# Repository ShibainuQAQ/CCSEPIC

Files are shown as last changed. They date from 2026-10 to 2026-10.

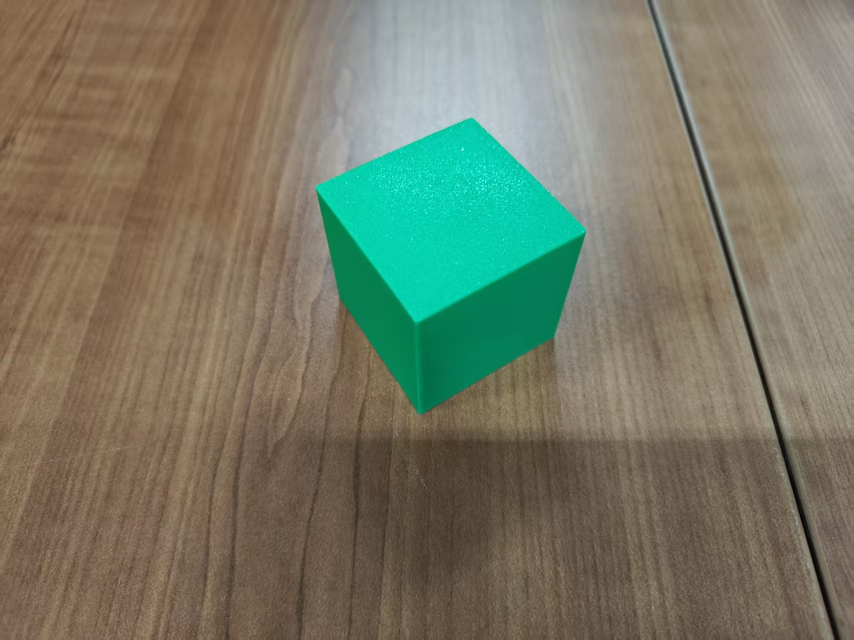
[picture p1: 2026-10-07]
工创赛物料/绿色-正方体.jpg

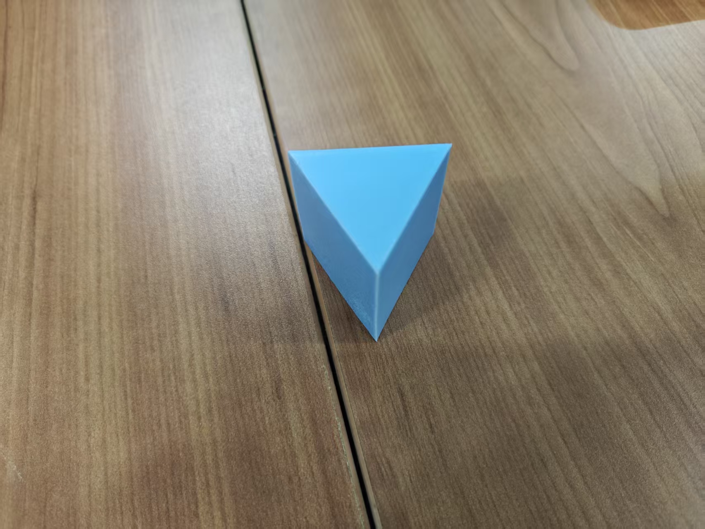
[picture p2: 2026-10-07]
工创赛物料/蓝色-正三棱柱.jpg

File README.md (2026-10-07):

# 工创赛 II-2 智能分拣 · 项目仓库

> 2026 年四川省大学生工程实践与创新能力大赛 · 项目 II-2「智能分拣」
> 龙门式三轴 + 舵机夹爪 · K210 视觉识别（经 PC 处理）· TJC 串口屏显示

---

## 一、任务简介

在 **350×350×450 mm** 的尺寸限制内，制作一台自动分拣装置：**6 个储物盒 + 分拣机构 + 托盘**。

- 待分拣物料边长/直径 ≤ 40 mm，一批 **≥ 12 件、≥ 6 种**（颜色 × 形状组合）
- **同形同色**的物料放入同一个盒，**单盒 ≤ 4 件**
- 每件物料须先**逐件显示**（屏上展示名称/图片/序号）再分下一件
- 物料在搬运中掉落即本轮结束

完整规则见 [`01_规则与命题/`](01_规则与命题/)（官方 PDF + 规则要点提取）。

## 二、总体方案（方案 B）

```
K210 摄像头拍照 ──USB串口(COM5)──▶ PC 端识别（OpenCV + HSV 阈值）
                                      │  两点标定：像素 → 龙门 mm 坐标
                                      ▼
                            PC ──USB-TTL CH340(COM14)──▶ STM32F103C8T6
                                                        ├─ 3× 步进电机（龙门 XYZ）
                                                        ├─ 舵机 Z 轴 / 舵机夹爪
                                                        └─ USART2 ──▶ TJC 串口屏（显示物料名称/图片/计数）
```

- **校赛形态**：K210 直接连 PC，识别与坐标解算全部在 PC 完成，STM32 只负责运动控制（有线，稳定优先）。
- **最终形态**：力争 K210 与 STM32 直连（USART3 已预留，尚未启用），并评估 ESP 无线链路（见 `11_ESP无线调试/`）。

## 三、硬件配置

| 模块 | 型号 / 关键参数 |
|---|---|
| 主控 | STM32F103**C8T6**（64 KB Flash / 20 KB RAM） |
| 视觉 | K210（CanMV_Yahboom 固件） |
| 步进电机 ×3 | 细分后 **80 步/mm**；TIM4 10 kHz 软件步进中断；最高 **5000 Hz ≈ 62.5 mm/s** |
| Z 轴舵机 | MG996R，TIM3-CH3 = **PB0**，50 Hz PWM，脉宽 611~2370 µs（611 = 最低点） |
| 夹爪舵机 | MG996R，TIM3-CH4 = **PB1**，50 Hz PWM，脉宽 750~2140 µs（1850 张开 / 950 闭合 / 2140 松爪投放） |
| 串口屏 | TJC 800×480，USART2（PA2/PA3，9600 8N1），显示物料名称 + 图片 + 序号 + 计数 |

物料实物照片（黄/绿/蓝 × 7 种形状）见 [`工创赛物料/`](工创赛物料/)。

## 四、通信速查

| 链路 | 接口 | 参数 |
|---|---|---|
| PC ↔ STM32 | USART1（PA9/PA10，USB-TTL CH340 = **COM14**） | 115200 **8E1** |
| PC ↔ K210 | K210 USB（**COM5**） | 115200 8N1 |
| STM32 ↔ TJC 屏 | USART2（PA2/PA3） | 9600 8N1 |
| STM32 ↔ K210（预留） | USART3（PB10/PB11） | 未启用 |

> COM 口编号以 `hw_bridge/tools/port_probe.py` 实测为准；无线桥（板载 ESP）已禁用。

## 五、目录结构

| 目录 | 内容 |
|---|---|
| `01_规则与命题/` | 官方规则 PDF、规则要点提取、物料图鉴 |
| `02_方案与说明书/` | 制作思路、校选方案说明书、阶段成果汇报 |
| `03_设计与尺寸/` | 夹爪设计参数、框架与布局尺寸 |
| `04_采购/` | 采购清单、选型问答 |
| `05_工具与校核/` | 布局校核、物料分析、STL/图纸小工具 |
| `06_参考与开源/` | 参考项目（SO-ARM 夹爪等） |
| `07_概念图/` | 框架结构概念图 |
| `09_固件/` | **STM32 固件**：`src/`（C 源码）、`keil/`（Keil 工程）、`build.py`、`flash_keil.ps1`、接线总表 |
| `10_屏幕图片/` | TJC 屏工具：`screen_show.py` 等脚本、图片 ID 对照表、屏内资源 |
| `11_ESP无线调试/` | ESP32-C3/C6 无线方案（固件、说明） |
| `08_视觉/` | **视觉链路**：`vision/`（识别+抓取主脚本）、`omv/`（K210 端）、拍照/REPL 工具 |
| `hw_bridge/` | **PC↔STM32 桥接**：`server.py`、`tools/`（手动控制/抓放脚本）、`protocol.md` |
| `工创赛物料/` | 21 种物料实物照片 |
| `Claude接续日志.md` | 全程接续开发日志（每日进展、踩坑记录） |

## 六、常用操作

```powershell
# 0) 探测串口
python hw_bridge/tools/port_probe.py

# 1) 回安全位（放置点正上方、Z 最高）
python hw_bridge/tools/go_safe.py

# 2) 手动控制（w/s=Z  a/d=夹爪  i/j/k/l=XY  mz/mg/mx=记录  p=状态  x=退出）
python hw_bridge/tools/manual_pick.py

# 3) 视觉引导抓取单件（拍照 → 识别 → mm 坐标 → 抓取 → 放置）
python 08_视觉/vision/vision_pick.py --color yellow --speed 5000 --zsettle 6.0 --zlift 5.0 --gsettle 0.35 --zdn 611 --drop

# 4) 连续抓取某颜色全部物料（第 1 件放 (0,0)，之后每件 -70 mm 排开）
python 08_视觉/vision/vision_pick_all.py --color green

# 5) 两点标定（视觉像素 → 龙门 mm）
python 08_视觉/vision/calibrate_2point.py --dist -40
```

固件：`09_固件/build.py` 编译、`09_固件/flash_keil.ps1` 烧录；协议见 [`hw_bridge/protocol.md`](hw_bridge/protocol.md)。

## 七、当前进度

- ✅ 龙门 XYZ + 舵机夹爪运动控制（软步进 10 kHz）
- ✅ 单件「视觉引导抓取 → 放置」全流程打通
- ✅ TJC 屏显示物料名称/图片/序号（`vis` 控件显隐语义已踩坑确认）
- ⏳ 按颜色连续抓取（`vision_pick_all.py` 已写好，待整机验证）
- ⏳ 形状稳定识别（俯视下 正方体↔正四棱锥、正三棱柱↔正四面体 无法区分，计划倾斜摄像头 20~30° 重标定）
- ⏳ 多盒分配策略（一盒一类、单盒 ≤4 件）、储物盒安装、IR 传感器验证
- ⏳ K210↔STM32 直连（USART3）

## 八、安全须知（重要）

1. **安全位置 = 放置点正上方 Z 最高**，它同时是 **+X 机械极限** —— 任何命令的 X 不得为正（脚本已强制拒绝，除非显式 `--allow-plusx`）。
2. 每次抓放流程以 `ZERO all` 归零开始（以启动时夹爪位置为原点），结束必须 **Z 升到最高、原地停住**，不做多余 XY 移动。
3. Z 轴与夹爪舵机**无位置反馈**，到位判断只能靠固定延时；延时异常变长通常意味着供电不足或机械卡滞（MG996R 堵转 ≈ 2.5 A）。
4. 紧急停机 = 直接断电；异响/顶死立即断电检查。

## 九、文档索引

| 文档 | 路径 |
|---|---|
| 规则要点 | [`01_规则与命题/II-2规则要点与搬运赛道对照.md`](01_规则与命题/II-2规则要点与搬运赛道对照.md) |
| 物料图鉴与识别标定 | [`01_规则与命题/物料图鉴与识别标定.md`](01_规则与命题/物料图鉴与识别标定.md) |
| 接线总表（C8T6） | [`09_固件/接线总表-C8T6-20261004.md`](09_固件/接线总表-C8T6-20261004.md) |
| 串口协议 | [`hw_bridge/protocol.md`](hw_bridge/protocol.md) |
| 屏端 UI 控件表 | [`10_屏幕图片/屏端UI控件表.md`](10_屏幕图片/屏端UI控件表.md) |
| 图片 ID 对照表 | [`10_屏幕图片/图片ID对照表.md`](10_屏幕图片/图片ID对照表.md) |

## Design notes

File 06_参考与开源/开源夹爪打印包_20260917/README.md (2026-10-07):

# 开源夹爪打印包（2026-09-17）

> **队内参考资料，不进比赛提交件。** 许可与来源见 `06_来源与许可.md`。
> 目的：给"龙门 XYZ + 托盘"的分拣机准备一套**能直接打印、抓得稳**的开源夹爪（验证件/对手件）。

## 3 分钟上手

| 步骤 | 做什么 | 去哪 |
|---|---|---|
| 1 | 切片 `01_打印文件\整版_SO-ARM夹爪_154x154_全部件.stl` → PLA+ / 0.2mm / 4 墙 / 25% 填充 / **不开支撑** | 9 个结构件一盘出（154×154×52） |
| 2 | 再打 `补打_固定销x2.stl`（**整版里缺这 2 个小销**）+ `爪垫_锯齿_70x14x2.stl` ×2（TPU 95A） | 齿条/齿轮想更顺可改 0.12mm / 100% 填充单打 |
| 3 | 按 `03_硬件清单与采购.md` 买舵机 / 轴承 / 导杆 / 螺钉 | 原样复刻 ≈ ¥300~420 |
| 4 | 按 `04_装配与调试.md` 装（9 步，含舵机限矩设置） | 关键：**Max Torque Limit = 500** |
| 5 | 抓不牢 / 抓不稳 → 看 `05_抓取稳定性.md` | 结论：瓶颈是**爪面摩擦**，不是夹持力 |

## 三条先知道

| # | 事项 | 说明 |
|---|---|---|
| ① | **它进不了我们的储物盒** | 夹爪外廓 **128（宽）× 109（深）× 130.5（高）mm**，我们盒内只有 **82×82**、盒口距台面 48 —— 塞不进去。用它只能**在盒口上方 20~30mm 投放**（详见 `00_索引与选型.md` §3） |
| ② | **合规** | 工创赛禁"成品套件拼装"、非标件须自主设计制造；A2 创意由专家打分、**同校外形雷同全 0**。这份包**只在队内用**：当验证件、当对手件、当构型参考；正式提交件仍用我方自研夹爪（76mm 宽、能进盒） |
| ③ | **舵机不通用** | 原设计用 **Feetech STS3215（12V 串行总线舵机，RS485/TTL）+ Waveshare 总线转接板**；我们已买的是 **DS3225（PWM，25kg，270°）**。两条路见 `03_硬件清单与采购.md` §2 |

## 目录

| 路径 | 内容 |
|---|---|
| `00_索引与选型.md` | 候选对比表 + 与我们整机的适配核对 + 推荐结论 |
| `01_打印文件\` | **打印就绪**：整版 STL、补打件、爪垫、拆好的单件、摆盘预览图 |
| `02_打印指南.md` | 材料/层高/填充/支撑/后处理/耗时耗材，逐件参数表 |
| `03_硬件清单与采购.md` | 官方 BOM → 国内可买对应表 + 两条舵机路线的取舍 + 预算 |
| `04_装配与调试.md` | 9 步装配（含我们接到 Z 轴要加的转接板）+ 常见故障排查 |
| `05_抓取稳定性.md` | 夹持力/摩擦/回差校核（带算式）+ 抓取姿态规范 + 验收测试 |
| `06_来源与许可.md` | 每个文件从哪个仓库来、什么许可、用它能干什么/不能干什么 |
| `07_其他开源方案\` | 其余候选（SSG-48 自适应夹爪等）的文档与取舍理由 |
| `01_打印文件\单件\` | 从整版拆出的 9 件（已重命名、已贴床），坏一件补一件用 |

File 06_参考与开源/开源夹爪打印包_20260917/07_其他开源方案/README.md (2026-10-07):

# 其他开源方案（本次搜到的其余候选）

> 队内资料，不进比赛提交件。完整对比见上一级 `00_索引与选型.md` §2。

---

## SSG48 自适应电动夹爪

| 项 | 内容 |
|---|---|
| 仓库 | `https://github.com/Source-Robotics/SSG-48-adaptive-electric-gripper`（182★，Apache-2.0） |
| 特点 | **自适应 + 力控**：抓取力 5~80N 可调，行程 48mm，质量 400g；爪指可换（Fin Ray 柔性指 / 实心指 / 尖指） |
| 驱动 | GBM5208-75 云台无刷电机 + **Spectral 无刷 FOC 驱动板（CAN 总线）** + AS5600 磁编码器 |
| 机加工件 | MGN7C 滑块 ×2 + 100mm 直线导轨 + 8mm 联轴器 + 黄铜热熔螺母 ×16 |
| 打印件 | 大件多（单个 body STL 20MB+），耗材与打印时间都不小 |
| 许可 | Apache-2.0 |

**为什么不选它当主推**

1. **驱动板是外部采购件**（source-robotics.com 的 Spectral micro BLDC，CAN 接口）—— 不是"买块舵机就能动"，
   要等货 + 调 CAN + 刷固件，赶工期不划算。
2. 打印量与装配量都远大于 SO-ARM 那套（9 件一版 vs 几十件大件）。
3. 我们需求其实很简单（≤40mm 方块、单件 ≤100g、抓力需求 <5N），**用不上 5~80N 的力控**。

**它值得留下的东西**

| 点 | 对我们的用处 |
|---|---|
| **Fin Ray 柔性指** 思路 | 抓异形/易碎件时，柔性指自动包络 → 若我方货物里有薄壳/纸盒件，可考虑在爪垫上做柔性结构 |
| 力控闭环（编码器 + 电流） | 我方若想判断"夹住了没有/夹多紧"，可参考它的传感方案（我们用总线舵机读负载更省事） |
| BOM 里的 MGN7C 微型导轨 | 与我方 Z 轴/夹爪导向选型是同一类件，可作采购对照 |

> 已下载：`README.md`、`BOM\BOM.md`、`LICENSE`、`SAFETY_WARNING_AND_DISCLAIMER.md`、`Assembly manual\Building_cables.md`。
> 需要它的 STL/STEP 时（单件 20MB+，全量 100MB+）：
> `python "05_工具与校核\gh_mirror.py" get Source-Robotics/SSG-48-adaptive-electric-gripper "<仓库内路径>" --out "_download/SSG48"`

---

## 只能人肉下载的（本机取不到）

| 方案 | 链接 | 为什么取不到 | 值不值得下 |
|---|---|---|---|
| Micro Servo Parallel Gripper（小型平行夹爪，开口 47mm） | https://grabcad.com/library/micro-servo-parallel-gripper-1 | GrabCAD 需登录 | **值得**：形态最贴合我们 82mm 盒口；但驱动是 SG90（力矩太小），要用得换 20kg 舵机并改舵盘接口 |
| Gripper for Servo MG996R | https://www.thingiverse.com/thing:6900287 | Thingiverse 需登录（403） | 一般：MG996R 驱动、CC BY-SA **带传染性**，与"匿名提交"冲突 |
| GRIPPER 标签合集（Printables） | https://www.printables.com/tag/gripper | Printables API 本机超时 | 需要更多灵感时可翻 |
| MSG 步进自适应夹爪（NEMA17，开口可调 200mm） | https://github.com/Source-Robotics/MSG-compliant-AI-stepper-gripper | 可下，但**本体 100/150/200mm 宽** | 不建议：进不了盒 |

---

## 本机网络实况（省得下次再试一遍）

| 通道 | 结果 |
|---|---|
| `github.com` / `raw.githubusercontent.com` 直连 | ❌ 不通 |
| `git clone` / `curl.exe`（Windows schannel） | ❌ `SEC_E_NO_CREDENTIALS (0x8009030E)` —— 换地址也一样 |
| `ghproxy.net` / `gh-proxy.com` + **Python urllib** | ✅ 可用 |
| `cdn.jsdelivr.net` | ❌ 仓库 >50MB 被拒 |
| `api.printables.com`（GraphQL） | ❌ 连接超时 |
| `thingiverse.com` | ❌ HTTP 403（页面里也没有直链 STL，下载要登录） |
| GitHub Search/REST API | ✅ 通（未登录 10 次/分搜索、60 次/时核心） |

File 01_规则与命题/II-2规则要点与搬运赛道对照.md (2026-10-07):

# II-2 智能分拣 · 规则要点与搬运赛道对照

> 依据：《2026年四川省大学生工程实践与创新能力大赛项目II-2：智能分拣项目命题和比赛规则.pdf》（四川省赛区组委会，2026 年 7 月发布，共 8 页，已放入本文件夹）。
> 本文 2026-09-15 由 Claude 用 PyMuPDF 提取全文整理（pdftotext 对该 PDF 提取失败——中文字体无 ToUnicode 映射；PDF 全文为文字、无场地示意图，只有表 1~3，已逐页核对无遗漏）。
> **一句话结论：II-2 是"静态智能分拣装置"，不是移动机器人——没有场地行驶、没有转盘原料区、没有任务码。原搬运方案的底盘/巡线/陀螺仪整套作废，视觉、主控、电源、显示思路大部分要重评。**

---

## 一、新旧赛道总对照

| 维度 | II-1 智能搬运（旧，已弃） | II-2 智能分拣（新，已报名） | 对我方影响 |
|---|---|---|---|
| 作品形态 | 全自主移动小车 | **静态分拣装置**（占地 500×500mm） | ❌ 移动底盘整套作废 |
| 尺寸限制 | 投影≤300×300、高≤400mm（臂可展开） | 整体 **350×350×450mm**（组合式也算整体尺寸） | 限高放宽 50mm，长宽加大 |
| 核心结构 | 底盘+升降台+夹爪 | **储物盒×6 + 分拣机构 + 托盘**（三件可组合可整体） | ➕ 全新机构设计 |
| 任务对象 | ≤80mm、≤100g 物料，6 色 | **≤40mm 见方**的货物，几何体+颜色+**污渍/缺陷图形、文字、二维码**；初赛 ≥12 件、≥6 种 | 货物小一半，识别维度多得多 |
| 视觉任务 | 扫二维码得任务码；认颜色；对圆环 | **AI 识别颜色+形状+文字+图像+二维码**，同形同色归一盒 | 笔记本+USB 摄像头升级为主力，OpenMV 吃力 |
| 显示 | OLED 显示四组任务码，字高≥12mm | **高亮彩屏，能播图片**；逐件显示：序号/货物名称/货物图片/分拣成功总数 | ❌ 2.42 寸单色 OLED 作废，换彩色屏 |
| 场地 | 2400×2400mm 车道场地 | 静态 500×500mm 区域 | 巡线、陀螺仪、定位全不需要 |
| 流程 | 扫码→取料→粗加工→暂存→码垛→返回 | 调试剩 30s 待机→抽签放货入托盘→一键启动→**逐件**分拣，每件存好后**先显示信息再分下一件** | 状态机完全不同 |
| 时间 | 每轮调试 3 分钟+运行 3 分钟，两轮取最好 | **相同**（每轮调试 3 分钟 + 运行 3 分钟，两次机会取最好） | ✅ 不变 |
| 15 秒规则 | 15 秒不动→本轮结束 | 15 秒无动作**或无显示**→本轮结束 | 类似，多了"无显示"判据 |
| 计分风格 | 按环数非线性计分（1环15分…） | **入盒计件**：单货一盒 2 分；同形同色多件同盒每个 5 分；混放不得分；**显示信息每条 2 分** | 满分策略=把同种货物归拢同盒 |
| 成绩换算 | A1/A2/A3 全按名次公式换算 | **A1 改为扣分制**（内容 15 + 排版 5，扣完为止）；A2 专家平均分；B1/B2 按名次公式 | 文档不再是"保底 12 分"，写好直接拿高分 |
| 提交材料 | 报到交 4 份文件+视频 | **任务命题文档 = "决赛任务命题方案"一份**（货物总数/种类/分拣时间/分拣要求；内容质量 15 分+排版 5 分） | 文档工作量大幅减少 |
| 匿名红线 | 同（出现校名姓名等→文档 0 分） | **同**（文档雷同、校名、姓名、队名、特殊标记→0 分） | ✅ 匿名纪律不变 |
| 决赛创新实践 | 4 小时现场做手爪+替换联调 | 4 小时按**现场发布的决赛任务命题**、用现场设备材料完成规定任务（细则另行发布） | 方向待定，强调现场工程能力 |
| 一键启动/禁遥控/单电源内置/允许笔记本通讯 | 有 | **全部保留** | ✅ 不变 |
| 比赛中更换零部件/电源 | 禁止 | 禁止（含调试） | ✅ 不变 |

---

## 二、II-2 规则要点（新赛道的"官方规则要点"，替代日志中搬运版）

### 1. 作品组成与硬性红线（不符合 = 取消资格/成绩）
- 作品 = **储物盒 + 分拣机构 + 托盘** 三部分（可分别制作赛时组合，也可整体式），非标零件必须自主设计制造，**禁止成品套件拼装**。
- **外形尺寸 ≤ 350×350×450mm（长×宽×高）**，无论整体式还是组合式。
- **储物盒 6 个，各自独立**，尺寸形状不限；必须保证分拣的货物（同盒不超过 4 个）能**完全**储存进盒。
  - **建模含义**：单盒内腔须按"**完全容纳 4 件 ≤40mm 货物**"校核，不能只按装 1 件做小；6 盒 × 4 件 = 装置理论容量上限 24 件。
  - **策划含义（写 A1 决赛任务命题方案时）**：同形同色的货物数量**不要超过 4 件**——规则给储物盒定的容量前提就是 4 件，超出即自相矛盾。
  - **初赛含义**：≥12 件且单盒 ≤4 件 → 至少占用 ceil(12/4)=**3 个盒**；均匀分到 ≥6 种时正好用满 6 盒。
- **托盘 ≥ 160×160mm，边缘高 ≥ 10mm**（防货物滑落）。
- 传感器、电机种类数量不限；控制系统种类不限、必须装在装置内；**鼓励采用 AI 技术**。
- **单电源**：只能用一个装在装置内部的电源，种类不限（禁液体/腐蚀污染类），比赛（含调试）中不可更换。**规则无电压上限**（与搬运赛道一致）。
- **允许与笔记本电脑通讯**；运行中不能碰笔记本；**禁止任何方式遥控**（用遥控装置不得参赛）。
- **一键启动**：裁判令下后一键启动；启动后选手再接触装置（含笔记本）→ 本轮结束。
- 比赛（含调试）中**不能更换任何零部件**。
- 显示屏：**高亮、仅显示功能（播放图片用）、能显示各种格式图片**及分拣信息。

### 2. 货物
- 常见几何体、常见颜色；货物上附有**模拟污渍和缺陷的图形、文字、二维码**等信息。
- 尺寸在 **40mm 正方形范围内**（含薄壁货物）。
- **同形状且同颜色的货物 → 放同一个储物盒**。
- 初赛货物 **≥12 件，种类 ≥6 种**（多形状多颜色）。
- 决赛物品按现场发布的决赛任务执行。

### 3. 现场初赛流程
1. 领队会抽签定上场顺序 → 检录 → 抽签定场地号。
2. 进场调试（每轮调试 3 分钟）；**调试剩 30s：停止调试、开电源待机**；同时抽签定本队货物，**裁判随机放入托盘**（位置和方向随机，队员不得触碰，否则本轮结束）。
3. 裁判令下 → **一键启动**，计时开始。
4. 逐件分拣：每分拣一件并存入储物盒后，**显示屏先显示本次分拣信息**（序号、货物名称、货物图片、分拣成功总数量），**然后才能分拣下一件**；信息未显示就分下一件 → 不得分。
5. **15 秒无动作或无显示 → 本轮结束**。
6. 直至完成所有货物分拣。每队**两次运行机会，取最好成绩**。

### 4. 现场初赛计分（A3，70 分）
- 储物盒中只有 1 个货物 → **2 分**。
- 多个**同色同形**货物放同一盒 → **每个 5 分**（货物必须全部入盒，未全入不计数）。
- 不同颜色或不同形状混入同盒（哪怕部分进入）→ 分拣错误，**不得分**。
- 一次只能分拣一件；只能分拣托盘中的货物；**分拣中掉落（装置内或装置外）→ 本轮结束**。
- 正确显示分类信息（序号/名称/图片/成功总数）→ **每条 2 分**；任何错误不得分。

### 5. 成绩构成
| 环节 | 项目 | 分数 | 评定方式 |
|---|---|---|---|
| 初赛 A1 | 任务命题文档 | 20 | **扣分制**（内容质量 15 + 排版规范 5，扣完为止）；雷同/校名姓名 → 0 分 |
| 初赛 A2 | 作品创意设计 | 10 | 现场专家打分取平均：创新性 4 + 美观性 3 + 合理性 3；**同校外形雷同全 0** |
| 初赛 A3 | 现场初赛 | 70 | 见上方计分 |
| 决赛 B1 | 创新实践 | 30 | 名次公式 `30 − 12/(N−1)×(名次−1)`；**4 小时内完成得满分资格，超时不得分**；未按命题完成任务取消后续资格；完成但未在后续比赛应用 → 扣决赛总成绩 50% |
| 决赛 B2 | 现场决赛 | 70 | 名次公式 `70 − 28/(N−1)×(名次−1)`，评分细则同初赛 |

- 同分排序：初赛总成绩同 → 现场初赛分高优先 → 运行时间短优先 → 抽签。决赛同理。
- 关键推论（与搬运不同）：**A1 是扣分制不是名次保底制**——文档写好就能拿满 20，写砸真扣分；排版规范独占 5 分，务必工整。

### 6. 必须提交的材料
- **任务命题文档 = "决赛任务命题方案"**：给出策划的货物分拣任务，含**货物总数量、货物种类、全部货物的分拣时间、具体分拣要求**。内容质量 15 分 + 排版规范 5 分。
- （注意：搬运赛道的"文件 1~4 + 3 分钟视频"结构是 II-1 的；II-2 规则正文只列了任务命题文档一项，**视频等其它材料要求以学校/组委会后续通知为准**。）

### 7. 奖项
- 名额由组委会按参赛队数赛前确定。"未能完成比赛"不参评：未准时参赛 / 严重安全事故或违纪 / 队员资格不符 / 作品不符主题 / 裁判组判定的其它情况。
- 结果公布 24 小时内不提异议不再受理。未尽事宜以组委会补充通知为准。

---

## 三、22 项硬件决策沿用性评审（✅ 2026-09-15 用户已确认评审结论，采购清单已按此重列）

### 大件 8 项（2026-09-11 拍板）

| # | 原决策 | 沿用性 | 说明 |
|---|---|---|---|
| 1 | Emm42 闭环步进 ×4（底盘） | **✏️ 改：数量 4→2~3，用途改为分拣机构驱动** | 装置不动了，但转盘/龙门轴仍需步进；Emm42 正好改做机构轴（数量随机构方案定） |
| 2 | USB 摄像头+笔记本扫码 | **✅ 沿用且升为主力** | AI 识别（形状/颜色/文字/二维码）跑笔记本 OpenCV；规则明确鼓励 AI、允许笔记本通讯 |
| 3 | 2.42 寸 OLED（SPI） | **❌ 作废** | 规则要求能播图片的高亮彩屏 → 换**彩色串口屏**（淘晶驰 3.5 寸级）或 SPI TFT |
| 4 | 6S 5000mAh 25C 航模电池 | **✏️ 改：容量大降** | 没有 4 个驱动电机，功耗大减；若机构用 24V 步进可留 6S 但 2200~3000mAh 足够，也可降 3S/4S——随机构方案定 |
| 5 | 双路 DC-DC（XL4015+LM2596） | **✅ 沿用思路** | 舵机一路+主控一路的架构不变，电压随新舵机定 |
| 6 | DS3225 舵机 ×3+备件 | **✅ 大概率沿用** | 夹爪/拨杆执行器；数量随机构方案定 |
| 7 | 8 路灰度阵列巡线 | **❌ 作废** | 无场地行驶 |
| 8 | 摆式悬挂+配重（本已暂缓） | **❌ 作废** | 无底盘 |

### 待拍板清单 14 项（2026-09-12 拍板）

| # | 原决策 | 沿用性 | 说明 |
|---|---|---|---|
| 1 | OpenMV H7 标准版 | **✏️ 降为辅助** | 形状+二维码+文字识别对 H7 吃力；可做装置端辅助（如入盒确认/兜底识别），也可不买——随视觉方案定 |
| 2 | 1080P USB 摄像头（锁曝光） | **✅ 沿用** | 俯视托盘做 AI 识别主力；锁曝光要求不变 |
| 3 | 96mm 麦轮 ×4 | **❌ 作废** | |
| 4 | 6S 5000~5200mAh 电池 | **✏️ 改** | 同大件 4 |
| 5 | XL4015+LM2596 | **✅ 沿用** | |
| 6 | MPU6050 | **❌ 作废** | 静态装置无需姿态（步进闭环自带位置反馈） |
| 7 | 8 路灰度模块 | **❌ 作废** | |
| 8 | 微动开关 ×5 | **✅ 沿用** | 机构原点/限位、夹爪到位检测照用 |
| 9 | 启动+急停按钮 | **✅ 沿用** | 一键启动是规则硬要求 |
| 10 | CH340 USB 转 TTL | **✅ 沿用** | 笔记本↔主控串口 |
| 11 | 总开关+保险丝+低压报警器 | **✅ 沿用** | 报警器随新电池串数定 |
| 12 | TRVV 拖链电缆 | **✅ 沿用** | 机构运动部件走线更需要拖链 |
| 13 | 联轴器/法兰 | **✏️ 重定** | 随新机构传动定（步进-丝杆/同步带轮） |
| 14 | 升降台方式（未定） | **❌ 作废，并入"分拣机构方案"重新设计** | |

### ➕ 新增需求（搬运方案没有的）
- **彩色显示屏**（能播图片）：串口屏最省事（图片预存屏内，串口发指令翻页）
- **入盒检测**：6 个储物盒各配到位检测（光电对射/反射或微动），因为"货物必须全部入盒才计分"
- **托盘货物定位**：俯视相机标定 + 坐标映射到机构坐标系
- **储物盒×6 + 托盘**结构件（3D 打印/玻纤板/亚克力）

---

## 四、分拣机构方案（✅ 2026-09-15 已拍板：方案 B 龙门 XYZ + 舵机夹爪）

**拍板结论：方案 B**。要点：
- **X/Y 轴**：Emm42 闭环步进（脉冲版）×2 + 同步带传动 + 光轴/直线轴承导轨（开源资料 2 教训：同步带精度高于齿轮齿条）
- **Z 轴**：只需"抓取低位/搬运高位"两个端点 → **DS3225 舵机 + 平行四边形连杆**（保持夹爪姿态），微动开关做到位检测；不上丝杆（负载 <100g，用不上）
- **夹爪**：DS3225 舵机 + 3D 打印夹爪（快拆模块，决赛创新实践可能要现场改制）
- **视觉定位**：USB 摄像头固定在托盘正上方俯视，九点标定把像素坐标映射到托盘平面坐标，直接对应龙门 X/Y 坐标系——这是选 B 的核心原因（相机坐标↔机构坐标一一对应，无运动学解算）
- **布局**：350×350mm 底板上，托盘（160×160）置前方正中，储物盒 2×3 排列于后方/两侧，龙门覆盖全部取放点（具体尺寸三维建模定）
- 步进由 4 套减为 **2 套**，舵机用量 2 个（Z + 夹爪）+ 备件

### 落选方案存档

| 方案 | 落选原因 |
|---|---|
| A. 舵机关节臂 | 开源资料 2 血泪教训：多舵机臂末端重复定位精度差；40mm 小货物+掉落即判负的规则下风险不可接受 |
| C. SCARA 转塔臂 | 需运动学解算、关节间隙影响精度；调试链路比龙门长，对新手队不划算 |
| D. 吹气/拨杆分度盘 | 货物随机姿态落盘不可控，"掉落→本轮结束"规则下直接否决 |

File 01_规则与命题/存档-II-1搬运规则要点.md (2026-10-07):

# 存档：II-1 智能搬运 · 官方规则要点（旧赛道，仅供参考）

> 本文 2026-09-15 由 `Claude接续日志.md` 移出。赛道已换 II-2 智能分拣，本节内容**不再权威、不再维护**，仅因《开源资料1~4》大量引用搬运规则且原 II-1 PDF 已丢失而存档备查。
> 原依据：《2026年四川省大学生工程实践与创新能力大赛项目II-1：智能搬运命题和比赛规则.pdf》（2026 年 7 月，12 页，图 1~图 6 为图片，PDF 已丢失待找回）。

## 一、硬性红线（踩了直接没成绩）
- **尺寸**：铅垂方向投影 ≤ 边长 **300mm 正方形**，高度 ≤ **400mm**（含所有软质线材）。**机械臂允许做成可折叠，出发后可自行展开，展开后尺寸不受限**。
- **电源**：**只能用 1 个装在车体内部的电源，电源种类不限**（不能用液体/有腐蚀污染的），**比赛过程中（含调试）不能更换**。→ **规则原文没有 12V 上限！**
- **一键启动**：车上必须有明确标识的"一键式"启动，**只有一次启动机会**；启动时间到没启动，本轮结束。
- **全自主**：不能用任何方式遥控。**但允许比赛过程中与笔记本电脑通讯**，只是运行中不能碰笔记本、不能遮挡场地（仅允许垂直向下补光）。
- **物料必须放在车上运**：不允许用手爪夹持物料运送；**每次抓1个，放到车上之后才能抓下一个**（车上可带 1~3 个）。物料没放到车上不能往下个区域走（本区域内不受限），否则不计成绩但计时照走。
- **放下即定局**：物料底面一旦接触地面即为放置完毕、按该位置定环数；**再移动该物料，本轮立即结束**。
- **不能推行**：把物料在场地推行移动 → 结束比赛。
- **不能出车道**：离开启停区后只能在灰色车道上行驶，铅垂投影越过车道（机械臂除外）进入其它颜色区域 → 本轮结束。
- **15秒不动**（等转盘时间另加 8 秒）→ 本轮结束。
- **掉落物料不取出**，自行取出 → 本队本轮结束。
- **禁止成品套件拼装**；除标准件外，非标零件必须自主设计制造。比赛期间（含调试）不能更换任何零部件。
- **任务码显示装置**：必须装在车上部醒目位置、**亮光显示**、不被遮挡、**字体高度 ≥ 12mm**，能显示所有任务码及完成情况信息。
- **文档匿名**：文档里出现地名、单位名、姓名、电话号码或无关特殊符号 → **任务命题文档 0 分**。

## 二、场地（2400×2400mm）
- 灰色行车道，中间十字车道宽 **400mm**；四个淡黄色区 450×450mm；其余亚光白色。
- **启停区 ×2**：300×300mm。
- **原料区**：顶面为**直径 300mm 的圆盘**，总高 80~100mm。**电动转盘**，转向随机，转盘上均匀放 3 个物料、**中线呈 120° 夹角**，匀速 **6~10 秒/圈**，停止位置有误差。初赛时转盘转向、停留次数和时间以现场为准。
- **暂存区 / 粗加工区**：各为 **580×150mm**，表面有测量摆放精度的**圆环 1~6 环**，圆环线宽 1.5mm，环中间标数字（就是这个数字决定放哪一环）。
- 原料区、二维码板位置**在规定范围内随机摆放**，以现场为准；各区域尺寸和摆放位置都有偏差，**车必须能适应**。

## 三、环号与分数（非线性，越靠内越值钱）
`φ` = 物料最大直径。环外径：1环 `φ+3`、2环 `φ1+5`、3环 `φ2+7`、4环 `φ3+10`、5环 `φ4+10`、6环 `φ5+10`

| 环号 | 1环 | 2环 | 3环 | 4环 | 5环 | 6环 | 6环外 / 倾倒 |
|---|---|---|---|---|---|---|---|
| 分数 | **15** | 10 | 7 | 5 | 3 | 1 | 0 |

判定方式：物料底面能看到某环的边缘，即算在该环内（图片见图6）。

## 四、物料
- 材质 3D 打印 ABS 或 PLA，**尺寸 ≤80mm，重量 ≤100g**。
- 初赛颜色：红、黄、蓝、绿、黑、浅蓝，**每种颜色两个**（现场会有色差，要能适应）。
- 初赛通过扫码确定需要搬运的**三种不同颜色**的物料，**三种颜色用同一种形状**。
- 决赛物料形状颜色多样（圆柱、方块、三角、球、锥、组合体等），现场公布。

## 五、任务码（⚠️ 是**四组**三位数，不是两组！）
- 共 **4 组三位数**，用 `+` 连接。颜色编号：**红1、黄2、蓝3、绿4、黑5、浅蓝6**。
- 第1组 = 第一批三个物料的**颜色和搬运顺序**
- 第2组 = 第一批物料在**粗加工区和暂存区**的放置位置（环号）
- 第3组 = 第二批三个物料的**颜色和搬运顺序**
- 第4组 = 第二批物料在**粗加工区**的放置位置（第二批在暂存区是码垛，位置由第一批决定，故不单独给）
- 例：`156+123+516+231` → 第一批顺序=红、黑、浅蓝，放在粗加工区/暂存区的 1、2、3 号圆环；第二批顺序=黑、红、浅蓝，放在粗加工区的 2、3、1 号圆环。

> ⚠️ 第2组的精确含义原文表述较含糊（"分别放置在粗加工区和暂存区的1、2、3号圆环上"）。**赛前找裁判或现场确认**：是粗加工区与暂存区共用同一组环号，还是各有分工。

## 六、二维码板
- 每个赛场内侧**垂直**安装 **1 块 A4 大小（横放）** 的二维码板，位置在规定范围内随机摆放。
- 二维码在板子中间，**尺寸 80×80mm（含边框）**，随机产生。

## 七、初赛流程（注意：粗加工区是**中转站**，要搬两次）
1. 扫码读任务码 → **把任务码显示在显示装置上**
2. 到原料区，按顺序从转盘上取第一批 3 个物料**放上车**（每次1个）
3. 携 1~3 个物料 → 运到**粗加工区**，按顺序放到规定圆环上
4. **再把粗加工区的物料取回车上** → 运到**暂存区**，按顺序放到规定圆环上
5. 返回原料区取第二批 3 个 → 重复 2~4（粗加工区）
6. 第二批在暂存区**只能在第一批物料上码垛**：要求**颜色一致**且第一批放置正确，不掉下即得分
7. 回到抽签确定的启停区，检查显示装置上"抓取正确次数 / 放置正确次数"统计是否正确

## 八、计分办法（原始分，用于排名）
1. 正确读二维码并在显示装置上正确显示 → **2 分**
2. 正确顺序码**持续显示到本轮结束** → **2 分**
3. 每正确抓取 1 个物料（抓到并放到车上）→ **2 分**
4. 粗加工区 / 暂存区**平面放置**按环计分（表见上），非线性
5. 暂存区**码垛**得分同第一批分数（不影响第一批平面放置成绩）
6. 规定时间内完成全部流程回到启停区 → **2 分**
7. 返回后正确显示"正确抓取数量 / 正确放置数量"，**各 2 分**（没抓没放则不得分）

## 九、时间与赛制
- 比赛前有 **5 分钟**场地调试时间。
- 比赛**分两轮**，每轮**调试 3 分钟 + 运行 3 分钟**，每队两次运行机会，**取最好成绩**。
- 调试剩余 **1 分钟**时抽签确定搬运任务；剩余 **30 秒**时车必须停止运行、放到出发位待机；助理裁判按抽签放好二维码板、随机摆物料并启动转盘。

## 十、成绩构成与换算（⚠️ 不是直接得分制）
| 环节 | 项目 | 分数 |
|---|---|---|
| 初赛 | 任务命题文档 A1 | 20（起评 12） |
| 初赛 | 作品创意设计 A2 | 10（起评 6） |
| 初赛 | 现场初赛 A3 | 70 |
| 初赛总成绩 A | | 100 |
| 决赛 | 创新实践 B1 | 30（起评 18） |
| 决赛 | 现场决赛 B2 | 70 |
| 决赛总成绩 B | | 100 |

**换算公式（按名次，N = 参赛队数）**：
- `A1 = 20 − 8/(N−1) × (名次−1)` → 区间 12~20
- `A2 = 10 − 4/(N−1) × (名次−1)` → 区间 6~10
- `A3 = 70 − 28/(N−1) × (名次−1)` → 区间 42~70
- `B1 = 30 − 12/(N−1) × (名次−1)` → 区间 18~30
- `B2 = 70 − 28/(N−1) × (名次−1)`

→ **关键推论**：分差被名次压缩，最后一名也能拿 12+6+42 = 60/100。所以**重点是把现场初赛名次顶上去**（A3 跨度 28 分，是三块里最大的），文档和创意设计保底即可、别翻车。文档匿名违规 = 直接 0 分，风险最大。

**同分排序**：初赛总成绩相同 → 现场初赛成绩高者优先 → 运行时间（完成全部任务）短者优先 → 抽签。决赛同分同理。

## 十一、必须提交的材料（初赛第一环节）
**报到时提交**，纸质版一式一份 + 电子版 1 份（**合并为一个 PDF**），共 4 份文件，各 5 分：
1. 作品结构设计方案（5分）
2. 作品控制系统电路设计方案（5分）
3. 决赛任务命题方案（5分）
4. 决赛任务场景策划（5分，含规划决赛场地、放物料区域及位置、物料放置方式，并给出物料形状、尺寸及零件图——工程图 + 三维图）

另需提交**与设计制作有关的不超过 3 分钟的视频 1 份**。除内容质量外，**排版规范、格式装订也计分**。

## 十二、作品创意设计（A2，10分）
- 创新性 4 分（符合主题、外形/内部结构有新意）
- 美观性 3 分（整体美观、合理、实用）
- 合理性 3 分（内外部结构合理、制造精细、拆卸方便）
- ⚠️ **同校作品外形雷同全部给 0 分**

## 十三、决赛
- **创新实践 B1（30分）**：现场抽签物料 → **手爪替换 + 机器人联调**。用现场提供的装备材料，现场设计制作零部件并替换原有零件安装调试。**4 小时内完成得满分，超过 4 小时此项不得分**。未按规定完成零件制作 → 取消资格；未把新加工零件换到作品上完成调试和后续现场运行 → **扣决赛总成绩的 50%**。自带拆装/调试工具。
- **现场决赛 B2（70分）**：流程参照初赛，按现场发布的决赛任务执行，两次机会取最好。

## 十四、奖项
一等奖 ≤10%、二等奖 ≤20%、三等奖 ≤30%。**"未能完成比赛"不参与评奖**（车不能启动 / 任一环节弃权 / 严重安全事故或不守纪律 / 队员资格不符 / 作品不符主题 / 裁判专家组判定的其它情况）。结果公布后 **24 小时内**未提成绩异议不再受理。

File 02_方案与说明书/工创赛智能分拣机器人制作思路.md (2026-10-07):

# 工创赛"智能分拣"赛项 · 制作思路（精简版）

> 面向：四川省赛 · 刚升大二的队伍 · 队内讨论用
> ✅ 已按官方规则核对：同文件夹内《2026年四川省大学生工程实践与创新能力大赛项目II-2：智能分拣项目命题和比赛规则.pdf》（2026年7月发布，共 8 页）
> ⚠️ **2026-09-15 已换赛道：智能搬运（II-1）→ 智能分拣（II-2），报名已确认**。本文已按 II-2 重写。
> 校选阶段一般只要求**方案说明书 + 三维建模**，正式细则以本校教务处/学院通知为准。

---

## 一、我们要做一台什么装置？

**不是车，是一台静态智能分拣机**——放在 500×500mm 的场地里不动，整体尺寸 ≤ 350×350×450mm，由三部分组成：

| 部分 | 要求 |
|---|---|
| **托盘** | ≥160×160mm、边缘高 ≥10mm；比赛时裁判把货物**随机**倒进托盘 |
| **分拣机构** | 我们的方案：**龙门 XYZ 机械手 + 舵机夹爪**（详见第五节） |
| **储物盒 ×6** | 各自独立；同形+同色的货物进同一个盒，每盒最多要能装 4 个 |

按一个按钮后自己完成：

```
俯视摄像头识别托盘里的货物（颜色+形状+文字/二维码）
→ 机械手逐个抓取（一次只能抓 1 个）
→ 放进对应的储物盒（同形同色归一盒）
→ 每放好 1 个，彩色屏先显示「序号/货物名称/图片/分拣成功总数」
→ 显示完了才能抓下一个
→ 直到 12 件以上货物全部分完
```

⚠️ 三个最容易记错的点：
1. **逐件分拣**：一次只能抓 1 个，**显示屏没显示本次信息就抓下一个 = 不得分**。
2. **掉货即终局**：货物掉在装置内或装置外 → **本轮直接结束**。
3. **混盒不得分**：不同颜色或不同形状进了同一个盒（哪怕只进去一半）= 分拣错误，不得分。

💰 **得分大头是"归堆归得对"**：同形同色的多个货物放进同一盒，**每个 5 分**；一盒只有 1 个只得 2 分；每条的显示信息全对每条再得 2 分。

## 二、红线规则（踩了直接没成绩，先背下来）

- **尺寸**：整体（含组合式三部分）≤ **350×350×450mm**；场地占用 500×500mm
- **托盘**：≥160×160mm、边缘 ≥10mm（防货物滑落）
- **储物盒**：**正好 6 个**、各自独立，每盒保证最多 4 个货物能**完全**装入
- **电源**：只能用 **1 个装在装置内部**的电源，种类不限，**赛中（含调试）绝对不能换**。规则**没有电压上限**
- **一键启动**：裁判令下后一键启动；启动后**再碰装置或笔记本 → 本轮结束**
- **全自主**：不能遥控（用遥控装置直接不得参赛）。**允许与笔记本电脑通讯**，但运行中不能碰
- **15 秒规则**：15 秒没有任何动作**或没有显示本次分拣信息** → 本轮结束
- **一次一件**：只能分拣托盘中的货物，一次只能 1 件
- 非标件必须自己设计制造，**禁止成品套件拼装**；赛中和调试期间都不能更换零部件
- **显示屏**：高亮彩屏、仅显示功能、**能播各种格式图片**（单色 OLED 不满足！）
- 文档匿名：**别写校名、姓名、队名、特殊标记**，出现即任务命题文档 **0 分**

## 三、货物与识别任务（先摸清要对付什么）

| 项目 | 参数 |
|---|---|
| 货物尺寸 | **≤40mm 正方形范围内**（含薄壁件）——比想象的还小 |
| 货物种类 | 常见几何体（柱/锥/球/方块…）× 常见颜色；初赛 **≥12 件、≥6 种** |
| 货物上的信息 | **模拟污渍和缺陷的图形、文字、二维码**——识别要能在有干扰的情况下工作 |
| 归类规则 | **形状相同且颜色相同** → 同一个储物盒 |
| 放置方式 | 裁判随机倒入托盘，**位置和方向随机**，队员不许碰 |

⚠️ 这意味着识别系统要同时搞定：**颜色分类 + 形状分类 + 抗污渍干扰 + 文字/二维码**（规则鼓励用 AI）。

## 四、比赛流程与计分（初赛）

**流程**：领队会抽签 → 检录 → 抽场地号 → **调试 3 分钟**（剩 30 秒停止调试、开电源待机，同时裁判抽签定货物并随机倒入托盘）→ 裁判令下**一键启动** → **运行 3 分钟**逐件分拣 → 每队 **2 次运行机会取最好**。

**现场初赛计分（A3，70 分）**：

| 情况 | 得分 |
|---|---|
| 储物盒里只有 1 个货物 | 2 分 |
| 同形同色多个货物同盒 | **每个 5 分**（货物必须全部入盒才算） |
| 不同颜色/形状混进同盒（部分进入也算） | **不得分** |
| 显示信息（序号/名称/图片/总数）每条全对 | 每条 2 分，有错不得分 |
| 没显示信息就分下一件 | 不得分 |
| 货物掉落（装置内外都算） | **本轮结束** |

💡 **策略推论**：尽量把同种货物归拢到同一个盒（5 分/件 vs 2 分/件，差 2.5 倍）；显示信息是白送的分，别因为程序 bug 丢掉。

## 五、推荐方案（预算约 1600~2200 元；明细见同目录《采购清单.md》）

**分拣机构 2026-09-15 已拍板：方案 B「龙门 XYZ + 舵机夹爪」**。为什么是它：

| 候选 | 为什么不是它 |
|---|---|
| 舵机关节臂 | 国特队血泪教训：多舵机臂末端重复定位精度差；货物只有 40mm、掉落直接判负，赌不起 |
| SCARA 转塔臂 | 要解运动学、关节间隙吃精度，调试链长 |
| 吹气/拨杆分度盘 | 货物随机姿态落盘不可控，"掉落=本轮结束"直接否决 |
| **龙门 XYZ** ✅ | 步进精度高、相机俯视坐标与机构坐标**一一对应**（标定简单）、结构成熟、新手成功率最高 |

| 模块 | 选型 | 为什么选它 |
|---|---|---|
| 主控 | **STM32F103RCT6** | 资料最多；2 路步进脉冲 + 2 路舵机 PWM + 串口屏 + 6 路入盒检测，资源够用 |
| 视觉 | **1080P 广角 USB 摄像头（可锁手动曝光）俯视托盘 + 笔记本跑 OpenCV** | 规则鼓励 AI、允许与笔记本通讯；形状+颜色+二维码+文字识别对笔记本是轻活，对单片机视觉模块是硬扛。⚠️ 摄像头硬指标是**能锁手动曝光**，下单前问客服。识别结果串口下发 STM32 |
| X/Y 轴 | **张大头 Emm42 闭环步进（脉冲版）×2 + 同步带 + 光轴导轨** | 闭环步进不丢步；同步带精度高于齿轮齿条（国特队教训）；⚠️ 下单选**脉冲版**别买 CAN 版 |
| Z 轴 + 夹爪 | **DS3225 舵机 ×2（Z 升降用平行四边形连杆 + 夹爪）+ 微动开关到位检测** | Z 只需"高位/低位"两个端点，舵机+连杆就够，不上丝杆；**必须限位开关到位检测，不许只用延时** |
| 入盒检测 | **反射光电开关 ×6（每盒 1 路）** | "货物全部入盒才计分"是硬规则，必须有硬件确认，不开环盲信 |
| 显示 | **淘晶驰 3.5 寸串口屏（480×320）** | 要高亮彩屏+播图片：货物图片按种类预存屏内，单片机串口发指令切换"序号/名称/图片/总数"。⚠️ 别买成裸 TFT |
| 电源 | **单包 6S 锂电 2200~3000mAh + 双路 DC-DC（XL4015 舵机 7.4V + LM2596 主控 5V）+ 6S 平衡充电器** | 没有行走电机，容量比搬运方案降半；24V 仍是步进驱动器推荐电压；**舵机和主控分开供电**（舵机一使劲主控就重启是灵异 bug 之源） |

> 🛒 杂项别漏：一键启动按钮 + 急停开关、CH340 USB 转 TTL、总开关 + 保险丝 + 6S 低压报警器、TRVV 拖链电缆（龙门运动走线反复弯折，国特队灰排线磨破烧 Jetson 的教训）、环形 LED 补光灯。

**架构一句话**：USB 摄像头 + 笔记本负责"看"（识别+定位，结果串口下发），STM32 负责"动"（X/Y 步进、Z 舵机、夹爪、状态机）+ 串口屏显示 + 入盒检测确认。

## 六、四步走路线（大二课业重，按周利用课余时间）

**第 1 步：让机构动起来（2~3 周）**
学 STM32 基础 → 步进驱动器接线（脉冲+方向）→ 定时器发脉冲+加减速 → X/Y 回原点（微动开关）→ 按坐标走位 → 舵机 Z 升降+夹爪开合+到位检测。
*里程碑：串口发"(x,y)"坐标，机械手能走过去抓起一个小方块放回原点。*

**第 2 步：让装置看得见（2~3 周）**
笔记本 OpenCV：俯视图像 → 颜色分割+形状分类（先规则法：轮廓/顶点数/圆度；再上 AI）→ 输出"种类+中心坐标+角度" → 九点标定把像素坐标映射到托盘坐标 → 串口发 STM32。
⚠️ 货物上有模拟污渍/文字/二维码干扰，**颜色形状识别要做抗干扰**（去噪、面积限幅、多次确认）。
*里程碑：托盘里放 6 种货物，屏幕打印出每种的名字和坐标，10 次对 9 次。*

**第 3 步：串起单件分拣全流程（2~3 周）**
识别 → 规划分拣顺序 → 抓取 → 入盒（光电确认）→ 串口屏逐件显示 → 再抓下一件。加入盒检测后做"显示→下一件"的严格时序。
*里程碑：6 件货物连续分拣，成功率 10 轮里 8 轮全对。*

**第 4 步：磨稳定性 + 提速（4 周以上）**
12+ 件压测、异常处理（抓空/卡货/识别存疑重拍）、3 分钟时间预算分配、外壳美观（A2 创意分 10 分看外形+内部结构）。
⚠️ **15 秒无动作或无显示就判负**——每个动作加超时重试，宁可放弃一件也不能卡死整轮。
*里程碑：连续跑 10 轮不死机，12 件 3 分钟内分完。*

## 七、新手最容易踩的 5 个坑

1. **舵机和单片机共电源** → 舵机一使劲单片机就重启，灵异 bug 之源，分开供电
2. **识别不做抗干扰** → 实验室调出阈值就不管，赛场光线不一样全崩；调试那 3 分钟就是干这个的（带旋钮/串口在线调阈值）
3. **只用延时不做到位检测** → 改一次动作链全乱；夹爪/Z 轴都用微动开关确认
4. **先抓下一件再显示** → 规则明文：信息没显示就分下一件不得分；状态机里"显示完成"必须是硬门禁
5. **一个环节卡死就死等** → 15 秒无动作本轮结束；每个动作加超时，识别存疑宁可重拍也不硬抓

## 八、成绩怎么算（别把力气用错地方）

| 环节 | 项目 | 分数 | 怎么评 |
|---|---|---|---|
| 初赛 | 任务命题文档 A1 | 20 | **扣分制**：内容质量 15 + 排版规范 5；雷同/出现校名姓名 → **0 分** |
| 初赛 | 作品创意设计 A2 | 10 | 专家现场打分取平均：创新性 4 + 美观性 3 + 合理性 3；**同校外形雷同全 0** |
| 初赛 | 现场初赛 A3 | 70 | 入盒计件（第四节表） |
| 决赛 | 创新实践 B1 | 30 | 4 小时现场命题任务（用现场设备材料）；名次换算 |
| 决赛 | 现场决赛 B2 | 70 | 流程同初赛；名次换算 `70 − 28/(N−1)×(名次−1)` |

⚠️ 和搬运赛道最大的不同：**A1 文档是扣分制不是名次保底制**——写好"决赛任务命题方案"（货物总数/种类/分拣时间/分拣要求）就能接近满分，写砸是真扣分。**文档值得我们认真写，它是性价比最高的 20 分**。

**报到要交**：任务命题文档一份（即"决赛任务命题方案"）。是否还要视频等材料，以学校/组委会后续通知为准。

⚠️ **决赛"创新实践"环节是 4 小时现场命题任务**（现场提供设备材料）→ 夹爪等执行件做成**可快速更换模块** + 带足备件和工具。
⚠️ **同校作品外形雷同，全部给 0 分**。

## 九、分工建议（3~4 人队）

- **1 人机械**：三维建模 + 3D 打印（龙门架/连杆/夹爪/储物盒/托盘）+ 装配（校选阶段任务最重）
- **1 人电控**：STM32、步进脉冲控制、舵机、入盒检测、串口屏
- **1 人视觉**：笔记本 OpenCV 识别（颜色/形状/抗干扰/二维码）+ 九点标定 + 串口协议
- **队长**：统筹 + 状态机整合 + 文档（**A1 文档 20 分扣分制**，性价比最高，别轻视）

## 十、入门学习清单（按顺序学，边学边做）

1. **C 语言 + STM32 入门**：B 站"江协科技 STM32 入门教程"（免费，新手口碑最好）
2. **步进电机控制**：脉冲 + 方向的原理、梯形/S 曲线加减速、回原点
3. **OpenCV（Python）**：颜色空间（HSV）分割、轮廓与形状特征（顶点数/圆度/Hu 矩）、`QRCodeDetector` 读二维码、相机标定与坐标映射
4. **三维建模**：SolidWorks 或 Fusion 360（校选要交三维模型，3D 打印件也用得上）
5. **串口通信**：STM32 和笔记本各会发会收，定个简单协议（如 `$类型,x,y,角度#`）；淘晶驰串口屏的上位机编辑器用法

## 十一、参考资料

**官方规则（最优先）**
- 同文件夹内《2026年四川省大学生工程实践与创新能力大赛项目II-2：智能分拣项目命题和比赛规则.pdf》
- 同文件夹《II-2规则要点与搬运赛道对照.md》——规则要点整理 + 硬件沿用性评审 + 机构方案对比

**四川赛区通知**
- [西南交通大学 2026 校选报名通知](https://sieetc.swjtu.edu.cn/info/1073/11321.htm)
- [西华大学 2026 校选通知](https://sma.xhu.edu.cn/b1/b3/c669a242099/page.htm)
- [四川大学校内选拔通知](https://jwc.scu.edu.cn/info/1069/9339.htm)
- 大赛官网：http://www.gcxl.edu.cn

**技术参考**
- **同文件夹 `开源\` 目录**：西安理工大学 2025 国特等奖开源方案（4 篇整理稿）。⚠️ 那是**搬运赛道**的移动机器人方案——底盘/巡线部分用不上，但**串口通信架构、闭环步进经验、同步带 vs 齿轮齿条教训、拖链电缆教训、模块化快拆理念**仍然通用
- OpenCV 官方文档、淘晶驰串口屏开发资料（官网有上位机和指令集）

> ⚠️ 开源方案许可为 **CC BY-NC-SA**：禁止商用倒卖，**禁止抄进我们的方案说明书**（比赛要求文档匿名、不抄模板），引用需署名。

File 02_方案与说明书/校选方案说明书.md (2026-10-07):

# 智能分拣装置 · 校选方案说明书

> 版本：2026-09-15（按本赛项 II-2 官方命题要求与评分细则编写）
> 说明：本说明书为匿名评审件，全文不出现校名、姓名、地名与赛项全称。

---

## 1 引言与赛项理解

### 1.1 赛项任务

本赛项要求自主设计并制作一台**静态智能分拣装置**：比赛时裁判将若干货物随机倒入托盘，装置在无任何人工干预的情况下，自动完成货物的**识别、分类与储存**——把形状相同且颜色相同的货物放入同一个储物盒，并在显示屏上逐件显示分拣信息。

### 1.2 规则要点摘要

表 1 规则硬性要求摘要

| 项目 | 要求 |
|---|---|
| 作品组成 | 储物盒 ×6 + 分拣机构 + 托盘（可组合式或整体式） |
| 外形尺寸 | 整体不超过 350×350×450mm（长×宽×高） |
| 托盘 | 不小于 160×160mm，边缘高度不小于 10mm |
| 储物盒 | 6 个独立储物盒；每盒须能完全容纳分拣入盒的货物（不超过 4 个） |
| 货物 | 尺寸在 40mm 正方形范围内（含薄壁件）；附有模拟污渍、缺陷的图形、文字、二维码等信息；初赛货物不少于 12 件、种类不少于 6 种 |
| 归类规则 | 形状相同且颜色相同的货物放入同一个储物盒 |
| 供电 | 仅允许 1 个装在装置内部的电源，种类不限，比赛（含调试）过程中不得更换 |
| 通讯 | 允许与笔记本电脑通讯；运行过程中不得触碰笔记本；禁止任何形式的遥控 |
| 启动 | 裁判指令后一键启动；启动后再次接触装置（含笔记本）本轮结束 |
| 显示 | 高亮显示屏（仅显示功能），支持各种格式图片播放；逐件显示序号、货物名称、货物图片、分拣成功总数量 |
| 时间与轮次 | 每轮调试 3 分钟 + 运行 3 分钟，两次运行机会取最好成绩 |
| 结束条件 | 15 秒无动作或无显示本次分拣信息，本轮结束；货物掉落（装置内或装置外），本轮结束 |

表 2 现场初赛计分规则摘要

| 情况 | 得分 |
|---|---|
| 储物盒中仅有 1 个货物 | 2 分 |
| 多个同色同形货物放入同一储物盒 | 每个 5 分（货物须全部入盒） |
| 不同颜色或不同形状货物混入同盒（含部分进入） | 不得分 |
| 正确显示分类信息（序号/名称/图片/总数） | 每条 2 分，有错不得分 |
| 信息未显示即分拣下一件 | 不得分 |
| 货物掉落（装置范围内或装置外） | 本轮结束 |

### 1.3 设计约束分析

由规则可提炼出四个对设计起决定作用的约束：

表 3 规则约束与设计对策

| # | 规则约束 | 对设计的要求 |
|---|---|---|
| 1 | 掉落即本轮结束，且货物仅 40mm 级 | 抓取与搬运环节的**可靠性与定位精度**是第一指标，机构选型向精度倾斜 |
| 2 | 同形同色归一盒计 5 分/件，混盒不得分 | 识别必须**形状+颜色双判据**，且要有入盒结果的硬件确认 |
| 3 | 逐件分拣，显示完成才能分下一件 | 软件状态机须把"显示完成"作为**硬门禁**，并配合超时机制规避 15 秒判负 |
| 4 | 货物随机倒入托盘，位置方向随机 | 必须**俯视成像 + 坐标标定**，先定位后抓取，不能用固定动作盲抓 |

## 2 机械结构设计

### 2.1 总体布局

装置采用**整体式**布局：底板（350×350mm 级）上，托盘位于前方正中，6 个储物盒分两列布置于后方两侧，龙门架横跨托盘与储物盒上方，俯视相机固定于托盘正上方。整机外形控制在 350×350×450mm 以内。

表 4 整机布局规划

| 区域 | 内容 | 备注 |
|---|---|---|
| 前方中部 | 托盘（160×160mm，边缘高 10mm） | 倒货区，货物随机落入 |
| 托盘正上方 | 俯视相机 + 环形补光 | 固定安装，视野覆盖整个托盘 |
| 后方两侧 | 储物盒 2 列 × 3 个 | 每盒配 1 路入盒检测 |
| 横跨上部 | 龙门架（X/Y 轴）+ Z 升降 + 夹爪 | 工作空间覆盖托盘与全部储物盒 |
| 底板下部/背部 | 主控、电源、驱动器、走线 | 模块化固定，便于拆装检修 |
| 醒目位置 | 彩色显示屏、一键启动按钮、急停开关 | 显示屏不被遮挡 |

### 2.2 分拣机构：龙门 XYZ + 电动夹爪

表 5 机构方案对比与选型（已定论）

| 候选方案 | 优点 | 缺点 | 结论 |
|---|---|---|---|
| 多自由度舵机关节臂 | 结构紧凑、外观科技感强 | 多舵机串联末端重复定位精度差，存在同赛事强队翻车先例；40mm 小货物+掉落判负规则下风险不可接受 | 放弃 |
| SCARA 旋转臂 | 结构较简单 | 需运动学解算，关节间隙影响精度，调试链路长 | 放弃 |
| 吹气/拨杆分度 | 机构最简单 | 货物随机姿态不可控，掉落风险高（掉落即本轮结束） | 放弃 |
| **龙门 XYZ + 电动夹爪** | 直角坐标系精度高、无运动学解算；相机俯视坐标与机构坐标一一对应，标定简单；结构成熟 | 结构件较多、外观偏"工业" | **选用** |

表 6 分拣机构各轴设计

| 轴 | 驱动 | 传动 | 定位方式 |
|---|---|---|---|
| X 轴（横移） | 闭环步进电机（脉冲版） | 同步带 + 光轴直线导轨 | 微动开关回原点 + 闭环步进位置控制 |
| Y 轴（纵移） | 闭环步进电机（脉冲版） | 同步带 + 光轴直线导轨 | 微动开关回原点 + 闭环步进位置控制 |
| Z 轴（升降） | PWM 舵机 | 平行四边形连杆（保持夹爪姿态） | 高位/低位两端点，微动开关低位确认 |
| 夹爪 | PWM 舵机 | 3D 打印夹爪（快拆模块） | 微动开关夹合到位检测 |

选型理由：闭环步进不丢步、位置可控；同步带传动精度高于齿轮齿条（同赛事强队曾因齿轮齿条精度损失分数的公开教训）；Z 轴仅需高位/低位两个端点，舵机加连杆即可满足，无需丝杆，简化结构。

### 2.3 托盘与储物盒

- **托盘**：3D 打印/板材制作，内空 ≥160×160mm，边缘高 10mm；底部平整、浅色哑光，兼顾货物防滑与视觉识别对比度。
- **储物盒 ×6**：3D 打印，独立可拆；盒口做导向斜面便于货物滑入；每盒侧壁开孔安装反射式光电开关，确认货物**完全入盒**（规则：未全部进入不计数）。内腔尺寸按**完全容纳 4 件 ≤40mm 货物**校核（规则要求每盒须能储存不超过 4 个货物），避免因容量不足被判不合格。

### 2.4 模块化与可维护性

- 各功能模块（龙门组件、夹爪组件、储物盒、电控仓）之间采用螺栓连接，**任一模块拆卸不超过 5 颗螺丝**；
- 夹爪为**快拆模块**：决赛创新实践环节需按现场命题改制执行件，快拆结构可最大限度压缩现场改制时间；
- 正式结构件加工前，先用木板/KT 板切样验证装配关系。

## 3 电控系统设计

### 3.1 总体架构

表 7 电控系统组成

| 模块 | 选型 | 职责 |
|---|---|---|
| 主控 | STM32F103RCT6 | 步进脉冲控制、舵机 PWM、状态机、串口通信、入盒检测 |
| X/Y 驱动 | 闭环步进电机驱动器（脉冲版）×2 | 接收脉冲/方向信号，闭环防丢步 |
| Z/夹爪 | 25kg 级 PWM 舵机 ×2 | 升降与开合 |
| 入盒检测 | 反射式光电开关 ×6 | 每盒货物落入确认 |
| 到位检测 | 微动开关 ×5 | X/Y 原点、Z 低位、夹爪到位 |
| 显示 | 3.5 寸串口彩屏（480×320） | 逐件显示序号/名称/图片/总数 |
| 通讯 | USB 转 TTL（CH340） | 笔记本识别结果下发 |

### 3.2 电源系统

表 8 电源分配方案

| 支路 | 电压 | 供电对象 | 实现方式 |
|---|---|---|---|
| 动力支路 | 24V 直通 | 步进驱动器 ×2 | 电池经总开关、保险丝直供 |
| 舵机支路 | 7.4V / 5A | 舵机 ×2 | 独立 DC-DC（XL4015） |
| 逻辑支路 | 5V / 3A | 主控、传感器、显示屏 | 独立 DC-DC（LM2596/Mini360） |

- 电源为**单包 6S（24V）锂聚合物电池**，装于装置内部，符合"单一内置电源、赛中不更换"的要求；
- **舵机与主控分开供电**并在舵机支路就近加储能电容，避免舵机大电流冲击导致主控复位；
- 配备电源总开关、保险丝、低压报警蜂鸣器、急停开关与带标识的一键启动按钮。

### 3.3 可靠性与安全

- 运动机构走线采用柔性拖链电缆，随龙门运动往复弯折不破皮（有赛事中排线磨破导致短路烧毁主控的公开教训）；
- 主回路串联保险丝；急停开关切断动力支路；
- 所有接插件焊接加固，线束整理固定，防止运行振动松脱。

## 4 视觉与识别系统设计

### 4.1 识别任务分析

规则要求识别货物的**颜色、形状、文字、图像、二维码**等信息，且货物带有模拟污渍与缺陷干扰。采用"**笔记本 + 俯视 USB 摄像头**"方案：规则明确允许与笔记本电脑通讯，识别结果经串口下发主控。笔记本算力充足，可运行 OpenCV 完成多特征识别，开发调试效率远高于嵌入式视觉模块。

### 4.2 识别流程

表 9 视觉识别流程

| 步骤 | 内容 |
|---|---|
| 1 取图 | 俯视摄像头固定拍摄托盘；锁定手动曝光 + 环形补光，压制环境光与频闪干扰 |
| 2 分割 | HSV 颜色空间阈值分割得到候选货物区域，形态学去噪、面积限幅（抗污渍干扰） |
| 3 分类 | 颜色直方图判色；轮廓特征（顶点数、圆度、长宽比、Hu 矩）判形状；`QRCodeDetector` 读二维码 |
| 4 定位 | 轮廓质心 + 最小外接矩形给中心坐标与姿态角 |
| 5 标定 | 九点标定建立像素坐标到托盘平面坐标的映射；托盘坐标系与龙门 X/Y 坐标系重合，直接换算目标点 |
| 6 下发 | 识别结果（种类、坐标、角度）经串口定长协议发 STM32 |

### 4.3 抗干扰与确认机制

- 连续多帧识别一致才采信，单帧异常直接重拍；
- 污渍/文字造成的伪轮廓用面积与形状特征双重过滤；
- 调试阶段预留串口在线调阈值接口，适配赛场光线差异。

## 5 软件流程设计

### 5.1 主状态机

表 10 主状态机状态表

| 状态 | 动作 | 转移条件 |
|---|---|---|
| 待机 | 上电自检、各轴回原点、屏显就绪画面 | 一键启动按下 |
| 识别 | 通知笔记本拍摄识别，接收货物清单 | 收到完整清单/超时重拍 |
| 规划 | 按"同形同色归一盒"生成分拣序列与目标盒号 | 序列生成完毕 |
| 取货 | X/Y 移至目标上方 → Z 降 → 夹合（到位确认）→ Z 升 | 夹爪到位开关闭合 |
| 放货 | X/Y 移至目标盒上方 → Z 降 → 松开 → Z 升 | 入盒光电触发确认 |
| 显示 | 串口屏刷新：序号/名称/图片/成功总数 | **显示完成后才允许进入下一件（硬门禁）** |
| 完成/异常 | 全部分完停机；任一动作超时进入重试或放弃该件 | 15 秒判据兜底 |

### 5.2 关键时序与异常处理

- **显示门禁**：状态机中"显示完成"是进入下一次抓取的强制前置条件，对应规则"信息未显示即分拣下一件不得分"；
- **超时与重试**：每个动作设超时；识别存疑重拍、抓空重抓（限次数），宁可放弃一件也不卡死整轮（15 秒无动作本轮结束）；
- **入盒确认**：光电开关未触发则视为未入盒，不计入成功数量，屏显不出现虚假计数。

### 5.3 通讯协议

笔记本 → STM32 单向串口下发，定长帧含帧头校验：货物种类编号、中心坐标、姿态角；STM32 → 串口屏为串口指令（图片与界面元素预存屏内，仅发切换指令，响应快、不占用主控资源）。

## 6 风险分析与对策

表 11 主要风险与对策

| # | 风险 | 后果 | 对策 |
|---|---|---|---|
| 1 | 抓取/搬运中货物掉落 | **本轮直接结束** | 夹爪做仿形内衬+包络式夹持；Z 升降降速；路径避开其它货物；抓取前视觉复核目标位姿 |
| 2 | 污渍/文字干扰导致误分类 | 混盒不得分 | 多帧确认、面积限幅、形状多特征联合判决；存疑重拍 |
| 3 | 赛场光线变化 | 识别率下降 | 锁手动曝光+自带补光；调试 3 分钟内在线调阈值 |
| 4 | 舵机无反馈导致动作不到位 | 抓空/碰货 | 全部动作配微动开关到位检测，禁止纯延时 |
| 5 | 步进低速振动、丢步 | 定位漂移 | 闭环步进防丢步；驱动器细分+加减速曲线抑制振动 |
| 6 | 线束磨破短路 | 设备损坏 | 拖链电缆+缠绕管理线，焊点热缩管绝缘 |
| 7 | 程序卡死 | 15 秒判负 | 全链路超时看门狗，任何环节可放弃当前件保底 |

## 7 进度计划

表 12 四阶段进度

| 阶段 | 内容 | 周期 | 里程碑 |
|---|---|---|---|
| 一 | 机构动起来：步进接线、脉冲与加减速、回原点、舵机与夹爪到位检测 | 2~3 周 | 按坐标走位并抓取小物块 |
| 二 | 装置看得见：颜色/形状/二维码识别、九点标定、串口下发 | 2~3 周 | 6 种货物识别正确率 90% |
| 三 | 单件分拣全流程：识别→抓取→入盒确认→逐件显示→下一件 | 2~3 周 | 6 件连续分拣成功率 80% |
| 四 | 稳定性与提速：12+ 件压测、异常处理、3 分钟时间预算、外壳美观 | 4 周以上 | 连续 10 轮不死机，12 件 3 分钟内完成 |

## 8 附图清单（三维建模完成后补入）

表 13 附图清单

| 图号 | 名称 | 状态 |
|---|---|---|
| 图 1 | 整机三维总装图 | 待补（三维建模中） |
| 图 2 | 龙门 X/Y 传动与导轨布置图 | 待补 |
| 图 3 | Z 升降连杆与夹爪机构图 | 待补 |
| 图 4 | 电源与电控布置图 | 待补 |

---

> 本说明书全部内容为参赛队自主完成；机械非标件均为自主设计并 3D 打印/加工，未使用成品套件拼装。

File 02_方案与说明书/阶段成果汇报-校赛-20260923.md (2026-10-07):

# 智能分拣装置 · 阶段成果汇报（校赛）

> 汇报日期：2026-09-23 ｜ 赛项：大学生工程实践与创新能力大赛 II-2 智能分拣
> 用途：向指导教师汇报项目当前进度与技术成果
> 配套材料：《校选方案说明书》（匿名评审件）、《采购清单》、《框架与布局尺寸》、《夹爪设计参数表》、固件源码与工具脚本

---

## 0. 一页速览

| 项 | 内容 |
|---|---|
| **赛题** | 静态智能分拣装置：货物随机倒入托盘 → 自动识别形状+颜色 → 分入 6 个储物盒 → 屏幕逐件显示 |
| **机构方案** | 已拍板 **方案 B：龙门 XYZ + 舵机夹爪**（经 3 方案对比论证，放弃多关节机械臂） |
| **整机尺寸** | 350 × 350 × 300mm（规则上限 350×350×450，**高度余量 150mm**） |
| **预算** | **约 1050~1600 元**（已剔除全部已有/自备件：步进电机、铝型材、工具、电源杂项等） |
| **投入产出** | 自研文档 **14 份 Word + 20 余份 Markdown**；自研脚本工具 **30+ 个**；固件已跑到 **fw 0.3.0** |
| **当前进度** | 框架已搭；固件主链路全部打通；视觉标定完成；**导轨/电机待装** |
| **距可跑通** | 主干仅剩 5 件，见 §10 |

---

## 1. 赛题理解与规则解析

拿到官方 8 页规则 PDF 后，第一时间完成全文解析并产出三份文档：

| 成果 | 内容 |
|---|---|
| 《II-2规则提取.txt》 | 规则原文逐条提取，供全队引用 |
| 《II-2规则要点与搬运赛道对照.md》 | 要点 + 与上一赛项（II-1 搬运）的逐项对照，**识别出本次已换赛道** |
| 《校选方案说明书》 | 按命题要求与评分细则编写的**匿名评审件**，13 张表 |

**从规则中提炼出 4 条决定设计走向的硬约束：**

| # | 规则约束 | 对设计的要求 |
|---|---|---|
| 1 | 货物掉落 = 本轮直接结束；货物仅 40mm 级 | 抓取与定位**可靠性优先于速度**，机构选型向精度倾斜 |
| 2 | 同形同色归一盒 5 分/件，混盒不得分 | 识别必须**形状+颜色双判据**，且入盒结果要硬件确认 |
| 3 | 显示完成才能分拣下一件；15 秒无动作判负 | 软件状态机须把"显示完成"做成**硬门禁** |
| 4 | 货物随机倒入，方向位置随机，队员不能碰 | 必须**俯视成像 + 坐标标定**，先定位后抓取，禁止固定动作盲抓 |

**计分风险点已全部拆解**：混盒（含部分进入）不得分、货物掉落本轮结束、显示有错该条不得分 —— 这三条决定了"宁可慢、不可错"的整体策略。

---

## 2. 方案选型（已拍板，附论证）

### 2.1 机构方案三选一

| 候选方案 | 优点 | 缺点 | 结论 |
|---|---|---|---|
| 多自由度舵机关节臂 | 结构紧凑、外观科技感强 | 多舵机串联末端重复定位精度差，**同赛事有强队翻车先例**；40mm 小货 + 掉落判负规则下风险不可接受 | ❌ 放弃 |
| 吸盘/真空 | 对规则货物（几何体）吸附不可靠 | 表面有污渍/缺陷图形，且几何体多为小平面 | ❌ 放弃 |
| **龙门 XYZ + 舵机夹爪** | 直角坐标重复定位精度高、控制简单、行程可校核 | 结构相对占地 | ✅ **选定** |

### 2.2 总体布局

- **整体式**：底板 350×350 级，**托盘在前、6 盒（3列×2排）在后**，龙门架横跨上方，俯视相机固定于托盘正上方
- 4040 铝型材框架，立柱落地，导轨梁 2×350 沿深向架在顶框上面，Y 梁吊挂
- 主控、电源、驱动、走线模块化布置于底板下部/背部；屏幕、启动按钮、急停置于醒目不遮挡位置

---

## 3. 机械设计：参数化设计 + 自动校核

> 这是本项目最有方法论价值的部分：**所有尺寸不是拍脑袋定的，而是由脚本按规则硬约束反算、并自动校核**。

### 3.1 框架与下料（4040 铝型材）

| 件 | 长 (mm) | 数量 | 位置 |
|---|---|---|---|
| 立柱 | 260（**待改 310**，见 §3.4） | 4 | 四角落地 |
| 底框横梁 | 270 | 4 | 贴地一圈 |
| 顶框横梁 | 270 | 4 | 顶面与立柱平齐 |
| 导轨梁（深向） | 350 | 2 | 顶框上面，架左右立柱顶面 |
| Y 梁（宽向） | 270 | 1 | 吊在两根导轨梁下面 |

下料合计 ≈4.2m（自备型材，**不进采购预算**）。

### 3.2 工作区布局（已定稿）

| 件 | 宽 X | 深 Y | 说明 |
|---|---|---|---|
| 托盘（外廓 160，壁 2.5） | 95 ~ 255（居中） | 2 ~ 162 | 规则 ≥160×160、边高 ≥10 |
| 储物盒 ×6（外宽 86 / 内腔 82 / 节距 88） | 44 ~ 306 | 168 ~ 342 | 盒组 262×174 |

- 内腔 82 ≥ 4 件 40mm 货所需 80 ✅
- 盒组宽 262 ≤ 内净宽 270（两侧各余 4）✅
- 盒组后沿 342 ≤ 350（余 8）✅
- 托盘与盒组间隙 6mm ✅

### 3.3 行程校核（脚本自动核，10 个取放点逐点全过）

| 轴 | 行程 | 需求 | 余量 |
|---|---|---|---|
| 深向（Y） | 350 − 滑块 45 = **305** | **289**（托盘前沿 y10 → 后排盒心 y299） | ✅ 16 |
| 宽向（X） | Y 梁 270 − 滑块 45 = **225** | **176**（x87 → x263） | ✅ 49 |
| Z（竖直） | 行程 70 | 65（触底 → 高出盒口 20） | ✅ |

**6 个盒心 + 托盘四角共 10 个取放点，深向/宽向逐点核对全部 ✅**（`布局校核报告.txt`）。

同时**主动发现一个次紧点**：深向"前探"差 12.5mm（托盘最前沿的小件够不着，40mm 大件本身够得着），已给出 4 条补救方案并推荐"夹爪相对滑块前移 15mm"（只改一块转接板孔位）。

### 3.4 夹爪 v2（参数化设计，红线全过）

**方案**：1 个 DS3225 舵机 → 小齿轮 → 两根对置齿条 → 两只夹爪（各 1 根 Ø6 导杆 + 2 个微型轴承约束）→ 浮动爪 + 压簧 + 微动开关，实现**恒力夹取 ≈5N + 触货确认**。

| 项 | 数值 | 依据 |
|---|---|---|
| 最大开口 | **64mm** | 40mm 方货斜放 45° 对角 56.6 + 误差 4 + 爪垫压缩 2 = 62.6 → 取 64 |
| 闭口 / 行程 | 8 / **56mm** | 单爪 28 |
| 舵机转角 | **152.8°** | θ = 行程/(2r)，r=10.5 → **必须买 270° 版 DS3225** |
| 爪板 | 厚 3.5 × 深 30 × 高 48，尖端楔形 1.5 | 手指要插进货与盒壁之间 |
| 传动 | 齿轮 M1.5-z14，两段齿带同时啮合上下两根齿条 | 避免两齿条互相干涉 |
| 本体 | 76 × 52 × 34，**总包络 82 高** | 装得进盒口上方又不碰盒壁 |
| 打印件合计 | ≈81g（上界，挖减轻孔可降到 60g 内） | 体积 × PLA 密度 |

**红线校核（`夹爪校核报告.txt`）11 项，10 项 ✅**：抓得住斜放 40mm 方货、整体下潜进盒（爪外廓 71 ≤ 内腔 82）、爪尖楔形可插进缝隙、舵机转角留余量、齿轮装得进主框、舵机同轴直驱、导杆全行程有支撑、包络正确、整机高度 ≤450。

**产出**：`gripper_design.py`（参数化算尺寸+校核+出图+出 STL）、`fusion_gripper.py`（Fusion 360 一键生成实体，833 行/19 个组件）、**11 个 STL 已出**、`夹爪图纸.png`。

**主动发现的 1 个红线问题（待队内拍板）**：内腔 82 + 爪厚 3.5 时，4 件 2×2 可放最大货边只有 **36.5mm**，要放 4 件 40mm 需内腔 ≥88。三条出路：① 换 3030 型材（内净宽 290 → 内腔 90）② 货物上限降到 ≤36 ③ 接受风险靠盒口导角+楔形爪尖提容错。

### 3.5 开源参考（合规使用）

调研 GitHub / Printables / Thingiverse / GrabCAD 后选定 **Robonine《SO-ARM100/101 平行夹爪》**（176★，硬件 CERN-OHL-P-2.0 / 文档 CC BY 4.0），**只借构型、不借零件**，来源与许可已单独成档。已做完整打印包：整版 STL 拆成 9 个单件、按真实件名重命名、补打原厂缺失的 2 个固定销、附 7 份 md+docx 说明。

**两条硬结论**：① 该夹爪 128×109×130.5mm **进不了我们 82mm 盒口** → 定位为验证件/构型参考，正式件仍用自研 v2（76mm 宽）；② 抓不稳的瓶颈是**爪面摩擦（PLA μ≈0.3）不是夹持力**（需求 1.8~4.9N/爪，可用 49N/爪，余量 10~27 倍）→ 对策 = TPU 爪垫 + 齿条齿轮 0.12mm/100% 填充 + 夹货物中上部。

---

## 4. 视觉与识别（基于实测标定，非假设）

### 4.1 货物标定样本

采集官方物料**实拍照片 20 张**（7 形状 × 3 色，缺"蓝色-正方体"1 张），并生成带中文标签的 **7×3 矩阵总览图**供全队对照。

### 4.2 颜色识别窗口（在 20 张实拍照片上实测统计）

| 颜色 | 张数 | H 中位 | H 5%~95% | S 中位 | 建议识别窗（OpenCV 口径） |
|---|---|---|---|---|---|
| 绿 | 7 | 83 | 77~85 | 248 | `H 71~90 & S≥190 & V≥110` |
| 蓝 | 6 | 101 | 100~104 | 150 | `H 93~109 & S≥90 & V≥150` |
| 黄 | 7 | 29 | 22~31 | 140 | `H 16~36 & S≥80 & V≥67` |

**三色 H 彼此间隔 ≥10，判别鲁棒**。同时识别出一个脆弱点：**黄色 H 22~31 与木地板（H 5~20）只隔几个色相单位** → 已定对策：黄判定加饱和度门槛 + 面积滤波、摆放台面用深灰哑光、只用白光照明。

### 4.3 俯视轮廓混淆矩阵（关键发现）

固定俯视相机看到的是投影，**有两组会撞车**：

| 俯视投影 | 可能来源 | 只看轮廓能否区分 | 解法 |
|---|---|---|---|
| 正方形 | 正方体、正四棱锥 | ❌ | **Z 轴下探测高**（棱锥只有方体约 40% 高） |
| 三角形 | 正三棱柱、正四面体 | ❌ | 高度 + 顶面是否可见矩形侧面 |
| 圆 / 六边形 / 五边形 | 圆柱 / 六棱柱 / 五棱锥 | ✅ 各自唯一 | — |

**推荐方案（零成本，硬件已具备）**：把 Z 轴当"高度探针"——在真正夹取前增加一次慢速轻触测高，卡住即停，下降行程即货物高度。**一次测量同时解决两组混淆**，还顺带得到抓取所需的精确下降深度，并提供"深度异常"的兜底判据。

### 4.4 屏幕显示图片（已处理完毕）

20 张货物原图（1706×1279 手机实拍）→ 统一裁成 **160×160**，处理方式为**按颜色自动框出实物 → 外扩留白 → 补正方形 → 缩放**，**20/20 全部自动框选成功**，并生成拼图逐张人工复核。配套 `图片ID对照表.md`（类别 → 图片 ID，运行时按 ID 调用）。

---

## 5. 固件（STM32F103RCT6，已跑到 fw 0.3.0）

### 5.1 架构定位

固件扮演 **"哑执行器 + 安全守门人"**：

- **哑**：只认 ASCII 行协议，收到明确命令才动，动完发事件回报，不猜意图
- **守门人**：**一切安全判断（软限位、未回原点禁动、急停）都在固件里**，上位机不做兜底

> 理由：AI/上位机会犯错（幻觉出越界坐标、命令发一半），让最不可能出错的一层兜住安全，是这套架构唯一站得住的理由。

**线协议 v1.0**：22 条命令、10 个错误码、事件/日志约定，`OK`=受理 / `EVT *_DONE`=完成的语义区分；**每条命令 ≤100ms 内必须回一行**。

### 5.2 已完成的里程碑（全部真机实测通过）

| 里程碑 | 状态 | 实测证据 |
|---|---|---|
| **M1 握手固件** | ✅ 验收通过 | `PING→OK pong`、`VER`、`STATUS`、`HELP`、`ERR 1 unknown`、`ERR 11 not homed` 全部实测 |
| **串口 ISP 自动烧录** | ✅ 打通 | 同步 → V2.2 → DEV_ID `0x0414` → 擦除 → 写入 → 回读校验通过；**不依赖 ST-Link** |
| **编译→烧录→自测全自动闭环** | ✅ | `build.py` + `flash_keil.ps1` 一条命令 |
| **M2 舵机 PWM** | ✅ 打通 | TIM3 双路 50Hz、1µs 分辨率；**Z 轴工作行程标定 600~2400µs**；实测有保位力矩；11 条舵机命令全通 |
| **M2 入盒红外** | ✅ 单路首测通过 | 分体对射，极性实测与固件语义一致；**去抖改为 20ms 非阻塞采样**（5ms×4 连续一致） |
| **串口屏闭环** | ✅ fw 0.3.0 | 淘晶驰 3.5″ USART HMI；回环自检定位到根因 = 出厂波特率 9600；**ASCII 与中文（GBK）两条路都已打通**；UI 实测屏上正确显示 |
| **时基可靠性** | ✅ | `MS?` 实测 MCU 与墙钟误差 **0.08%** |

### 5.3 排障成果（10 个真 bug，全部定位并修复）

这部分是本次汇报中**最能体现工程能力**的内容 —— 每个 bug 症状都极具迷惑性，全部靠自建诊断手段定位：

| # | Bug | 症状（极难查的原因） | 定位手段 |
|---|---|---|---|
| 1 | **向量表下标 = 16 + IRQn**（误写 `[37]`） | 一开中断就跳到地址 0 跑飞；**偏移错了不报错** | RAM 启动脚印 |
| 2 | `GPIOA->CRH` 高低位写反（`0x4B0` 误写 `0xB40`） | TX 配成输入、RX 配成输出 → "固件在跑、串口一个字节出不来" | 寄存器快照进 RAM |
| 3 | 不要用 `__main` | 固件卡在 scatterload / rt_lib_init | 改为自己做 RW 拷贝 + ZI 清零 |
| 4 | **`USART_CR1.M` 字长语义** | F1 上 M 是"含校验位在内"的字长，`M=0+PCE=1` 实际只发 **7 数据位**，PC 按 8E1 读就把校验位当第 8 数据位 | 量化字节账 18→14 |
| 5 | **漏接共地 → MCU 不停复位** | 症状极隐蔽：回复里夹着一条 30 秒前的 banner、夹爪自己跳回中位；**还同时解释了"时基落后 1.8s"和"应答延迟 1.7~5.7s"两个怪现象** | 补共地后立刻不再复位 |
| 6 | 屏出厂波特率 9600 而按 115200 发 | **屏完全不响应且屏幕上毫无异常表现**，是本项目最难查的一类问题 | 回环自检 + 寄存器回读 + 下拉测试 + **垃圾指令探波特率**（决定性一步） |
| 7 | 中文 UTF-8 vs 屏 GBK 字库 | ASCII 正常、中文乱码 | `LCDRAW <hex>` 走 GBK 字节 |
| 8 | 去抖不足（1ms 再采一次不够） | 实测 1ms 内连跳三次 → M4 联调会让 AI 误计数 | 实测日志时间戳 |
| 9 | 对射式"两半没对准" | **误判方向反直觉**：没对准 = 报"有货"，不是报"没货"；临界对准时 19 秒内翻转 25 次 | 状态翻转时刻记录 |
| 10 | 桥 `SerialLink.open()` 成功时不清 `_last_error` | 返回的错误是上一次失败的残留，**被误导 4 次** | 交叉比对 |

**自建的诊断方法论（可复用）**：**RAM 启动脚印**（把"跑到哪一步"写进 SRAM → 复位回 bootloader → 用 Read Memory 读出来），把"板子毫无反应"变成了可判定的事实，是定位 bug 的关键。

### 5.4 引脚与硬件接口（已定稿并实测）

| 部件 | 接口 | 状态 |
|---|---|---|
| 主控 | STM32F103RCT6 最小系统板（板载 CH340K = COM6） | ✅ 实测为高密度 F103 |
| X/Y 步进 | STEP / DIR / EN 脉冲（自备，3.3V 直连） | ⚠️ 待装 |
| Z 轴 / 夹爪 | DS3225 舵机 ×2（TIM3 CH3=PB0 / CH4=PB1） | ✅ PWM 已通，夹爪已接 PB1 |
| 原点/限位/触货 | 微动开关 ×8（用 4 备 4） | 已购 |
| 入盒检测 | 红外对射 ×6（接 PC0~PC5，**3.3V 供电**，非 5V 容忍脚） | 单路已测，10 对已到货 |
| 串口屏 | USART3 / PB10 / PB11，8N1 @9600 | ✅ 闭环 |
| 烧录 | ST-Link V2 ／ 串口 ISP 兜底 | ✅ 两条路都通 |

---

## 6. 上位机接入与工具链（30+ 自研脚本）

为"AI 能直接驱动硬件"搭了一条完整工具链：

| 类别 | 工具 | 作用 |
|---|---|---|
| **硬件桥** | `hw_bridge\server.py`（10 个工具）+ `protocol.md` | 串口收发 / 相机抓拍回传 / **MCU 烧录（AN3155）**，让 AI 直接操作板子与相机 |
| **布局校核** | `layout_check.py` | 外廓/红线/10 取放点逐点行程覆盖，输出《布局校核报告.txt》 |
| **框架校核** | `maycad_check.py` / `maycad_view.py` | 读 MayCAD `.scene`，红线校核外廓/总高/立柱顶/导轨行程/Y 梁净空 |
| **夹爪设计** | `gripper_design.py` / `fusion_gripper.py` | 参数化算尺寸 + 校核 + 出图 + 出 STL；Fusion 一键生成实体 |
| **STL 处理** | `stl_tool.py` / `grip_pad_gen.py` | 量尺寸 / 拆件 / 摆盘 / 正交渲染；**自研 TPU 锯齿防滑爪垫生成器** |
| **视觉标定** | `material_analysis.py` / `material_sheet.py` / `img_tool.py` | 批量分析物料照片出 HSV 统计；拼 7×3 矩阵总览图；货物图片 160×160 自动框选 |
| **固件构建** | `build.py` / `flash_keil.ps1` / `tools\`（9 个诊断脚本） | Python 驱动 armclang（无 make）；编译→烧录一条命令；波特率/校验位扫掠、舵机点动标定、原始抓包 |
| **文档流水线** | `md转word.py` / `docx_colors.py` | Markdown → Word（用 Word 自身排版引擎）；**提取 Word 批注 + 字体颜色**（用于带色批注的清单回收） |
| **下载镜像** | `gh_mirror.py` / `gh.py` / `gh_scan.py` | GitHub 镜像下载器（调研开源方案用） |

---

## 7. 采购与预算

**已按"剔除全部已有/自备件"重列**，预算 **约 1050~1600 元**（原 1600~2200，省下步进电机、铝型材、3D 耗材、电源杂项、全部工具）。

| 类别 | 小计 |
|---|---|
| A 主控 | 35~70 元 |
| B 视觉 | 70~120 元 |
| C 运动与执行（舵机+线轨+同步带+光轴+夹爪增补） | 390~570 元 |
| D 传感器 | 30~45 元 |
| E 显示 | 60~90 元 |
| F 电源（只剩电池+充电器） | 280~430 元 |
| G 线材与连接 | 95~130 元 |
| H 结构材料（板材/标准件） | 90~130 元 |
| **合计** | **约 1050~1600 元** |

**三批下单策略**：① 立即（到货周期长且"动起来/看得见"阶段全要用）：主控、相机、补光、舵机（270°版）、电池+充电器 ② 建模前（便宜件一次凑齐）③ 建模定稿后**按图买**（同步带长度、导轨长度、光轴长度、板材尺寸全部按三维图定，不拍脑袋）。

**已完成的选型闭环**：18 张表的《选型问答整理》覆盖补光灯、同步带、MGN 导轨、角码、电缆、硅胶线、储物盒放置、入盒传感器、清单 9 条批注逐条解答 —— 每项都给出**决定性数值**而非模棱两可。

---

## 8. 文档体系（14 份 Word + 20 余份 Markdown）

| 目录 | 内容 |
|---|---|
| `00_待办与拍板\` | 待拍板事项通俗版（给队友的白话版，每项"要定什么/为什么/推荐哪个"） |
| `01_规则与命题\` | 规则原文提取、要点对照、**物料图鉴与识别标定**（7 张表） |
| `02_方案与说明书\` | 制作思路、**校选方案说明书**（匿名评审件，13 张表） |
| `03_设计与尺寸\` | **框架与布局尺寸**、**夹爪设计参数表**、夹爪目录（源码/STL/图纸/校核报告/交接/用法） |
| `04_采购\` | 采购清单（10 张表）、选型问答整理（18 张表） |
| `05_工具与校核\` | 全部脚本 + 布局校核报告 |
| `06_参考与开源\` | SO-ARM 开源夹爪（含许可合规）、成包打印包（36 文件）+ 7 份说明 |
| `08_发给队友\` | 夹爪设计包（18 文件 ZIP，可直接发） |
| `09_固件\` | 固件源码、Keil 工程、构建/烧录/诊断脚本、**固件设计-协议与引脚**、线路交接文档 |
| `10_屏幕图片\` | 20 张 160×160 货物图 + 图片 ID 对照表 + 总览拼图 + 队友包 |
| 根目录 | **Claude接续日志.md**（905 行，项目全程可追溯的工程日志） |

---

## 9. 当前进度总览

**主干 5 件（做完即可跑通全流程）：**

| # | 主干件 | 状态 | 已完成 | 剩余 |
|---|---|---|---|---|
| 1 | **框架 + 导轨 + 电机 → 能动** | 🟡 | 框架**已搭**；布局/行程校核全绿；下料表定稿 | 导轨/电机**未装**；滑块转接板待解决 |
| 2 | **夹爪 → 能抓** | 🟡 | 参数化设计完成、红线 11 项过 10、**11 个 STL 已出**、舵机已接 PB1 并标定全开 2400µs | 空载建表（µs↔mm 曲线）→ 打印 → 装配 |
| 3 | **相机 → 认得出颜色和形状** | 🟢 | USB 1080P 相机到货并验证抓拍；**HSV 窗口已实测**；混淆矩阵已分析、解法已定 | 识别算法集成；Z 轴测高接入 |
| 4 | **6 盒 → 放得对** | 🟡 | 坐标定稿、10 取放点校核全过、传感器留口设计定稿 | 盒体打印；传感器安装 |
| 5 | **全流程 12 件 × 3 分钟** | ⬜ | 固件主链路全通、屏幕 UI 已通、20 张货物图已入库 | 串联 + 调试 |

**固件侧已完成**：握手 / 舵机 / 入盒检测（单路）/ 串口屏 / 时基 / 烧录闭环 —— 全部真机实测通过，fw **0.3.0**。

---

## 10. 下一步计划（按主干顺序，砍掉非必要项）

| 优先级 | 事项 | 说明 |
|---|---|---|
| **P0** | 装导轨 → 装电机 → **单轴点动跑通** | 这是唯一能验证"整条链没白做"的事，今天必须见绿 |
| **P0** | 滑块转接板（买成品 ¥10~25，不自己设计） | 解开当前唯一机械卡点 |
| **P0** | 夹爪空载建表（2400/2200/2000/1800/1600/1400 各量爪口内宽）→ 插值算"爪口=40mm" | ⚠️ 教训：**不能盲驱**（会顶到止挡，红线 700µs） |
| **P1** | 相机识别算法（HSV 三窗 + Z 轴测高） | 窗口数据已备好 |
| **P1** | 6 盒打印 + 传感器安装 | 盒体按内腔 83 建模（留 1mm 收缩余量） |
| **P2** | 串联全流程 + 屏幕"显示完成才下一件"硬门禁 | 规则计分关键 |
| **挂起** | 入盒红外 6 路（规则不要求）、侧光判形状、补光 12V 改造、角码数量优化 | 全部延后，主干优先 |

---

## 11. 需要拍板 / 需要老师支持的事项

### 11.1 队内待拍板 4 件

| # | 事项 | 推荐 | 为什么现在要定 |
|---|---|---|---|
| ① | 立柱 **260 → 310**（框架返工） | **加长**（型材还没切，现在改零成本） | 夹爪真实包络 82 高，不是老参数表的 26 |
| ② | "每盒 4 件 40mm"三选一 | 换 3030 型材 / 货降到 ≤36 / 接受风险 | 内腔 82 + 爪厚 3.5 → 最大只放得下 36.5mm 货 |
| ③ | 托盘外廓 160 → 162~165 | **做 162~165** | 160 贴规则下限，打印收缩即违规 |
| ④ | 前探补救（差 12.5mm） | **夹爪前移安装 15mm** | 只改一块转接板孔位 |

### 11.2 希望老师支持

1. **场地/时间**：需要能连续跑 3 分钟调试的场地，以及打印设备的使用时段（6 盒 + 托盘 + 夹爪整套用量不小）
2. **技术指导**：夹爪 v2 的 Fusion 干涉验证（脚本已写好，尚未在 Fusion 里跑过）；以及"每盒 4 件 40mm"这个规则冲突的裁决建议
3. **物料补充**：入盒红外 6 路已到货（10 对），但 MGN 导轨/同步带等第三批"按图采购"的件需尽快定稿下单，避免影响装配进度
4. **展示材料**：如需现场演示，我们已有整套可展示物 —— 参数化设计脚本、自动校核报告、固件源码与实测日志、20 张物料标定图、屏幕 UI 与货物图库

---

## 附录 A：本阶段关键数字速查

| 类别 | 数字 |
|---|---|
| 整机外廓 | 350 × 350 × 300mm（限 350×350×450） |
| 托盘 | 外廓 160（建议 162~165）、边高 ≥10 |
| 储物盒 | 6 个，外宽 86 / 内腔 82 / 节距 88，盒组 262×174 |
| 深向行程 | 305（需求 289，余 16） |
| 宽向行程 | 225（需求 176，余 49） |
| 夹爪开口 | 64mm（闭口 8、行程 56、单爪 28） |
| 夹爪包络 | 82 高 × 76 宽 × 66 深 |
| 舵机转角 | 152.8° → **必须 270° 版 DS3225** |
| 恒力夹取 | ≈5N（需求 1.8~4.9N/爪，可用 49N/爪，余量 10~27 倍） |
| 颜色窗口 | 绿 H71~90 / 蓝 H93~109 / 黄 H16~36 |
| 取放点校核 | 10 个点 × 2 轴 = 20 项，**全部 ✅** |
| 红线校核 | 夹爪 11 项过 10；布局 7 项全过 |
| 固件版本 | fw 0.3.0（M1/M2/屏幕/入盒/时基 全部真机通过） |
| 自研工具 | 30+ 脚本 |
| 文档 | 14 份 Word + 20 余份 Markdown |
| 预算 | 1050~1600 元（已剔除自备件） |

---

## 附录 B：汇报时可展示的材料清单

| 展示物 | 路径 |
|---|---|
| 校选方案说明书（匿名评审件） | `02_方案与说明书\校选方案说明书.docx` |
| 框架与布局尺寸（含行程校核） | `03_设计与尺寸\框架与布局尺寸.docx` |
| 夹爪设计参数表 + 校核报告 + 图纸 | `03_设计与尺寸\夹爪设计参数表.docx`、`夹爪\夹爪校核报告.txt`、`夹爪图纸.png` |
| 布局校核报告（20 项全绿） | `05_工具与校核\布局校核报告.txt` |
| 物料图鉴与识别标定（含 HSV 实测） | `01_规则与命题\物料图鉴与识别标定.docx` |
| 货物矩阵总览图 | `工创赛物料\_总览_物料矩阵.jpg` |
| 屏幕货物图库 + ID 对照表 | `10_屏幕图片\总览_成品拼图.png`、`图片ID对照表.md` |
| 采购清单（10 张表） | `04_采购\采购清单.docx` |
| 选型问答整理（18 张表） | `04_采购\选型问答整理-20260917.docx` |
| 待拍板事项（白话版） | `00_待办与拍板\待拍板事项-通俗版.docx` |
| 固件设计文档（协议/引脚/状态机） | `09_固件\固件设计-协议与引脚.md` |
| 团队工程日志（905 行全程可追溯） | `Claude接续日志.md` |
| 夹爪设计包（可发队友） | `08_发给队友\夹爪设计包_20260917.zip` |

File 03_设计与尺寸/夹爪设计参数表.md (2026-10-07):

# 分拣夹爪设计参数表（平行两指 · 齿条同步 · 恒力夹取）

> 2026-09-16 立；**2026-09-17 复核修订到 v2（见 §0，开口 50→64、真实包络 26→82）**。**这份是三维建模的输入，也是第三批采购的依据。**
> **配套工具（2026-09-17 新建）**：`夹爪\gripper_design.py`（参数化算尺寸 + 校核 + 出图纸 + 出 STL）、`夹爪\fusion_gripper.py`（Fusion 360 一键生成实体）、`夹爪\用法.md`。**数值以工具输出为准，本文档解释"为什么这么定"。**
> 上游依据：方案 B「龙门 XYZ + 舵机夹爪」（已拍板）；构型参考：`参考\SO-ARM夹爪\`（Robonine 的开源平行夹爪，**只借构型、不借零件**，来源与许可见该目录 `来源与许可.md`）。

**一句话方案**：1 个 DS3225 舵机 → 小齿轮 → **两根对置齿条** → 两只夹爪（各由 **1 根 Ø6 导杆 + 2 个微型轴承**约束）→ 一侧做成**浮动爪 + 压簧 + 微动开关**，实现**恒力夹取（≈5N）+ 触货确认**。

> ⚠️⚠️ **2026-10-02 实装反馈（线路 A 代记，直接冲击本表核心前提，请勿忽略）**
> **实际装到机构上的是 MG996R —— 标准 ~180° 模拟舵机，不是本表要求的 DS3225 270° 版。**
> - **空载实测**（用 `09_固件\tools\servo_angle.py` 建表）：**1400→2400µs 只走了 23.2mm 爪口**（36.8mm → 60.0mm）；
> - 按本表 **r=10.5** 反推，这 1000µs 里舵机只转了 **≈63°**，折算全量程 500~2500µs 只有 **≈127°**
>   （若实装齿轮 r≈8 则 ≈166°）→ ✅ **2026-10-02 已由用户实测确认：该舵机可达角度只有 20°~150°**
>   **（行程 130°，≈722~2167µs）** —— 与上面独立反推的 ~127° 几乎一致，两个证据互相印证。
>   ⚠️ 顺带解释了历史上两次"顶死"：**700µs = 撞在 20° 那头的内部止挡**、**2500µs = 撞在 150° 那头**。
> - **冲击 ①** 开口端实测 **60mm**（设计 64mm）—— 仍够"40mm 货斜放 45°"所需的 56.6mm ✓；
> - **冲击 ②** 全量程爪口行程线性外推只有 **≈46mm**（设计 56mm）→ **闭口端可能到不了 8mm，小件夹不住**；
> - **冲击 ③** 所以第 39 行"**须买 270° 版 DS3225**"**不是可选项**，是硬约束。
> **待拍板**：① 换 DS3225 270° 版 ／ ② 改齿轮比 ／ ③ 就用 MG996R，但**必须配"微动开关触到就停"**
> （否则"位置式夹取"对货物尺寸敏感：夹大件堵转、夹小件够不着）。
> 明细见 `Claude接续日志.md` 线路 A 的 2026-10-02 条、`09_固件\src\board.h` 的舵机注释。

---

## ⚠️ 0. 2026-09-17 复核修订（v2）——先看这节，下面 §1~§2 的旧值部分已被取代

**起因**：核对"夹爪要缩到多少比例刚刚好"时，重读了规则原文与几何关系，发现三处问题。**新数值由 `夹爪\gripper_design.py` 参数化算得，可复跑**（报告：`夹爪\夹爪校核报告.txt`，图纸：`夹爪\夹爪图纸.png`，STL 与 Fusion 生成脚本同目录，用法见 `夹爪\用法.md`）。

### 改动 1：开口 50 → **64**（这条最要紧）

规则第 2 条写"货物尺寸在 40mm 的正方形范围内"，但流程写**"裁判随机放入托盘中……货物放置时的方向和位置随机，参赛队员不能自行触碰"**。40mm 方货**斜放 45°** 时，沿爪子开合方向占 **40√2 = 56.6mm** —— 开口 50 会顶在货的角上（抓不住 / 推飞，而**掉落 = 本轮结束**）。

算式：开口 ≥ 56.6（对角）+ 2×2（定位误差）+ 2×1（爪垫压缩）= **62.6 → 取 64**。

### 改动 2：夹爪真实包络 **≈82mm 高**（老参数表的 26 只算了框体）

26 没算两根齿条 + 齿轮 + 舵机。真实尺寸链：爪板 48（夹持面 Z 0~48）+ 传动/齿条 30 + 框顶 4 = **82**。它直接决定框架高度：

> 爪底高位 = 盒口 48 + 抬升 20 = 68（台面上）→ Y 梁底面需离地 250 → **立柱顶 310 → 整机 ~350**（规则上限 450 ✅）
> **现定稿立柱 260 要加长 ~50mm。型材还没切，现在改零成本。**

### 改动 3：发现"每盒 4 件 40mm"与"爪子伸得进盒"冲突（待拍板）

放货时手指必须插在货与盒壁之间 → 盒内腔 ≥ 2×货宽 + 2×爪厚 + 余量。
内腔 82、爪厚 3.5 时，**4 件 2×2 能放的最大货边只有 36.5mm**；要放 4 件 40mm 需内腔 ≥88，而 4040 立柱下 3 列最多 87。三条出路（需队内拍板）：① 换 3030 型材（内净宽 290 → 内腔 90 ✅）② 货物上限降到 ≤36（写进 A1 任务命题方案，但初赛货物由裁判随机 → 有风险）③ 接受风险，靠盒口导角 + 楔形爪尖提容错。

### 参数对照（旧 → 新）

| 项 | 旧（v1） | **新（v2）** | 依据 |
|---|---|---|---|
| 最大开口 | 50 | **64** | 40√2 + 余量 |
| 闭口 / 行程 / 单爪 | 4 / 46 / 23 | **8 / 56 / 28** | 开口 − 闭口 |
| 舵机转角 | 125° | **152.8°**（r=10.5） | θ = 行程/(2r)；**须买 270° 版 DS3225**（180° 版则齿轮改 M1.5-z16，本体高 30） |
| 爪板 | 厚 8 × 深 30 × 高 25 | **厚 3.5 × 深 30 × 高 48**，尖端楔形 1.5 | 手指要插进货与盒壁之间；爪顶要高过货顶，好让传动走在货上方 |
| 齿轮 | M1.5 z14 | **M1.5 z14（不变）**，但做成**两段齿带**同时啮合上下两根齿条 | 上下齿条错开布置，避免互相干涉 |
| 齿条 | 长 50 / 齿区 ≥43 | **长 52 / 齿区 44**，两根上下错开 | 行程 28/爪 + 啮合余量 |
| 导杆 | Ø6 × 60 | **Ø6 × 62**（每爪 2 轴承不变） | 跟爪板行程 |
| 本体 | ≈92×45×26 | **76(X) × 52(Y) × 34(Z)**，夹爪总包络 82 高 | 装得进盒口上方、又不碰盒壁 |
| 主框质量 | ≤70g | 打印件合计 **≈75g**（主框实心壁算上界，挖减轻孔可再降 30~40%） | 体积 × PLA 密度 |

> 其余结论（恒力 5N 浮动爪 + 微动开关、齿条同步自定心、导杆双轴承、只借构型不借零件、采购增补 6 行）**全部不变**。

---

## 1. 目标与边界（硬约束，先看这张）

> ⚠️ 本表为 v1 原文留档，其中"开口 50 / 本体 26 / 内腔 86"等数值已被上面 §0 修订，**引用请以 §0 与 `gripper_design.py` 为准**。

| 约束来源 | 数值 | 对夹爪的影响 |
|---|---|---|
| 规则：货物 ≤40mm 见方 | — | **最大开口 50mm**（单侧留 5mm 余量） |
| 规则：单盒 ≤4 件 | 4 件 40mm 需 80×80 | **盒内腔 ≥86×86mm** → 夹爪下潜净空足够 |
| 规则：装置整体 ≤350×350×450 | — | 夹爪本体控制在 ~92×45×26mm |
| 规则：托盘 ≥160×160、边高 ≥10 | — | 托盘与盒阵排布由建模定 |
| 规则：**掉落（装置内外）→ 本轮结束** | — | 必须恒力夹取 + 导向约束 + 低速，不允许"靠摩擦赌一把" |
| 规则：单电源内置、禁遥控、一键启动 | — | 夹爪由主控 **PWM 直接驱动**，不引入总线舵机/额外电源域 |
| 规则：禁止成品套件拼装、非标件自主设计制造 | — | 全件自己建模打印；**不直接使用参考件 STL** |
| 我方拍板：舵机用 DS3225（25kg·cm，无反馈） | — | 位置靠**机械硬限位**，抓力靠**弹簧**，不靠舵机角度 |

---

## 2. 关键参数（可照此建模）

> ⚠️ **本表为 v1 留档，不要照此建模**——请用上面 §0 的 v2 数值，或直接跑 `python 夹爪\gripper_design.py`（它会算出全套尺寸与校核）。

| 项 | 值 | 依据 / 算法 |
|---|---|---|
| 最大开口（两爪内侧面间距） | **50 mm** | 货 ≤40mm + 单侧 5mm |
| 闭口（最小开口） | **4 mm** | 留间隙，避免空合撞击 |
| **全行程** | **46 mm** | 50 − 4 |
| 单爪行程 | **23 mm** | 双齿条对置，各走一半 |
| 爪板 | 厚 8 × 深 30 × 高 25 mm | 货 ≤40mm，深 30 足够夹稳；爪垫另贴 2mm |
| 传动 | 舵机 → 齿轮 → **2 根对置齿条** | 对称开合 = **自定心**（抓取中心自动对准货心） |
| 齿轮模数 / 齿数 | **M1.5 / z = 14** | Ø顶 24.0、Ø分度 **21.0**、全齿高 3.375（0.2mm 层高≈17 层，好打印） |
| 舵机转角 | **≈125°** | θ = S/(2r) = 46/21 = 2.19 rad |
| 齿条 | 长 **50 mm**、齿区 ≥43 mm | 23 行程 + 20 啮合余量 |
| 导向 | 每爪 **1 根 Ø6 导杆**（长 60mm）+ **2 个 MF106ZZ**（6×10×3 带法兰） | 每杆双支撑，抗倾覆比参考件（每杆 1 轴承）更稳 |
| 本体外形 | **≈ 92 (开合向) × 45 × 26 mm** | 参考件 128 宽对应 84 行程；按行程比例缩 |
| 质量目标 | 打印件 **≤70 g**（+ 舵机 ~60 g） | 参考件 170g；我们货轻，不需要那么壮 |
| 目标抓力 | **5 N（弹簧恒定）** | 打印/泡沫方块足够；防夹坏、防堵转 |
| 开合时间 | 全行程 ~0.3s（空载；带载按 2~3 倍估） | 舵机 0.15s/60° 口径 |

### 运动学核算（改参数时重新算这三行）

1. 齿轮分度圆半径 **r = m·z/2 = 1.5 × 14 / 2 = 10.5 mm**
2. 两爪间距变化 = **2·r·θ** → θ = 46 / 21 = **125.5°**（180° 舵机够用，两端各留 ~25° 余量做硬限位）
3. 下潜净空：开口状态整爪外廓 = 50 + 2×8 = **66 mm** < 盒内腔 86 mm ✅（单侧余量 10mm）

---

## 3. 恒力夹取（我方差异点，建议写进 A2 创意）

舵机**没有力反馈**，位置式夹取会"按尺寸变化夹不紧 / 夹坏货 / 长时间堵转发热"。我们的做法：

| 状态 | 机构行为 | 电控行为 |
|---|---|---|
| 空载闭合 | 压簧把**浮动爪**推到最前，微动开关**未触发** | 舵机继续按指令合拢 |
| 触到货物 | 浮动爪被顶退 1.5~2mm，压簧压缩 → **微动开关触发** | **立即停止舵机**（不再给角度） |
| 保持 | 夹持力 = 弹簧力 ≈ **5N**，与货物尺寸/硬度无关 | 舵机仅需维持极小保持力矩（≈0.5 kg·cm），不发热 |

**好处**：① 力恒定、不夹坏；② 不堵转；③ 自带"夹住了"的**事件判据**，替代"只用延时"（我们文档里已定"不许只用延时"的原则）；④ 浮动量 ~3mm 覆盖货物尺寸差异，不必按尺寸分档。

---

## 4. 与参考件（SO-ARM 夹爪）对照

| 项 | 参考件 | 我方 | 为什么改 |
|---|---|---|---|
| 全行程 | 84 mm | **46 mm** | 货 ≤40mm，过大反挡盒口/蹭邻盒 |
| 整机尺寸 | 128 × 109 × 130.5 | ~92 × 45 × 26 | 整机 ≤350×350×450，要留盒阵+托盘 |
| 质量 | 170 g | ≤70 g | 负载 <100g，Z 轴只用舵机 |
| 驱动 | 总线舵机 STS3215（12V + 适配板 + 编码器） | **DS3225（PWM）** | 主控是脉冲/PWM 体系；省总线适配板与 12V 支路 |
| 夹持力 | 120 N | **5 N** | 120N 会把小方块夹坏 |
| 导向 | 每杆 1 轴承 | **每杆 2 轴承** | 抗倾覆更稳（防掉落） |
| 相机支架 | 夹爪上挂 RealSense/USB 相机 | **不用** | 我们相机固定在龙门横梁俯视，随机标定会更复杂 |
| CAD | 有 STEP + STL | 全自建 | 规则要求非标件自主设计制造 |
| 成本 | ~$62（≈450 元） | 增补 **25~40 元** | 舵机沿用已有 C2 |

**值得学它的三点**：① 齿条**同步对置**（自定心、消隙）；② **导杆+轴承**约束运动、驱动件只当推杆；③ **先打孔径测试件选配合**（Ø6.0~6.3 四档）。

---

## 5. 采购增补（Δ 清单，加进《采购清单.md》C 类）

| 项 | 数量 | 参考价 | 说明 |
|---|---|---|---|
| MF106ZZ 带法兰微型轴承 6×10×3 | 4 + 2 备 | 1~2 元/个 | 每爪 2 个做导向 |
| Ø6 导杆 | 2 根 × 60mm | 光轴 ~5 元/根 ／ **碳管 Ø6×4 更轻（~4g/根）** | 二选一；光轴耐磨、碳管减重 |
| 压簧（预压 3~5N，外径 ≤6，长 10~15） | 2 + 几种刚度 | ~0.5 元/个 | 恒力夹取，**买几种试刚度** |
| 微动开关 | C7 由 5 个 **改 6~8 个** | ~1 元/个 | 触货判据（X/Y 原点 2 + 夹爪 1 + Z 低位 1 + 备 2） |
| 爪垫：TPU 打印 或 3M 泡棉垫 2mm | 1 套 | ~5 元 | 增摩擦 + 限峰值力 |
| M1.5 成品齿条 100mm（可选兜底） | 1 | ~5 元 | 自打印齿隙大时对比/替换 |
| **合计** | | **约 25~40 元** | **舵机沿用 C2 的 DS3225，不新增** |

> ⚠️ 齿轮与齿条**自打印**（100% 填充、0.15mm 层高），不买成品套件 —— 既是规则要求，也省件。

---

## 6. 打印与装配要点

| 件 | 填充 | 层高 | 备注 |
|---|---|---|---|
| 齿轮、齿条 | **100%** | **0.15 mm** | 齿面强度直接决定夹持与寿命 |
| 主框 | 20~30% | 0.2 mm | 3~4 圈墙 |
| 夹爪 | 30% | 0.2 mm | 爪垫另贴 TPU/泡棉 |
| 导杆孔 | — | — | **先打孔径测试件（Ø6.0/6.1/6.2/6.3）挑配合**，再按选定孔径打夹爪 |

**装配顺序**：① 齿轮拧到舵机盘（4×M3 顶丝，压紧无间隙）→ ② 齿条侧插进夹爪并用销固定 → ③ 导杆穿入夹爪 → ④ 轴承压入主框（法兰朝上）+ M4 固定 → ⑤ 两爪对置穿入轴承 → ⑥ 装浮动爪压簧与微动开关，调预压 3~5N → ⑦ 舵机装主框，齿轮同时啮合两根齿条 → ⑧ 手动全程开合无卡滞后通电，**实测硬限位（闭口 4 / 开口 50）** → ⑨ 顶部 4×M3（30×30 阵列）接 Z 滑块转接板。

---

## 7. 风险与对策

| 风险 | 对策 |
|---|---|
| 打印齿条齿隙大 → 爪晃、重复定位差 | 齿条 100% 填充 + 0.15 层高；**齿轮中心距留 +0.3mm 调整垫**；必要时换成品 M1.5 齿条 |
| 舵机堵转发热 / 夹坏货 | **恒力弹簧（5N）+ 触货微动开关立即停**，禁止顶死 |
| 导杆与打印孔配合松/紧 | 照抄参考件"孔径测试件选档"；孔松了可换 ±0.1mm 档重打 |
| 掉落（=本轮结束） | 恒力夹取 + 双轴承导向 + 爪垫摩擦 + 低速位移；Z 轴另加导向（见 §9 待拍） |
| 货物二维码/文字被爪遮挡 | 抓取**前**俯视拍照识别；爪垫窄（12mm），只在夹持瞬间遮挡 |
| 齿条/齿轮磨损（决赛要连打多轮） | 多打 2 套备用件；夹爪做成**快拆**（4×M3），正好对上"决赛 4 小时现场换手爪" |
| 浮动爪弹簧刚度选错（夹不紧或夹太死） | 买 3 种刚度实测；弹簧力 = 目标 5N 反算 |

---

## 8. 三维建模顺序（Fusion 360 落地）

1. **先定储物盒（内腔 82×82×45，v2）→ 盒阵 2×3（262×174）→ 托盘 160（建议建模 162~165）** —— 一切尺寸的源头，夹爪尺寸最后由它校核。**推荐直接跑 `夹爪\gripper_design.py` 出全套尺寸，再在 Fusion 里跑 `夹爪\fusion_gripper.py` 生成实体**
2. 夹爪本体：开口 50 / 闭口 4 / 行程 46、爪板 8×30×25
3. 齿轮齿条：M1.5、z=14、r=10.5、齿条长 50、舵机转角 125°
4. 导杆与轴承座：Ø6、MF106ZZ、孔径分档测试件
5. 浮动爪 + 压簧 + 微动开关座
6. 与 Z 滑块/龙门横梁的转接板（4×M3，30×30）
7. 装配干涉检查：下潜外廓 71 < 内腔 82 ✅（v2）；**夹爪总包络 82 高 → 立柱 ~310**；整机总高 ≈350 ≤450 ✅；然后出说明书第 8 节的**图 3（Z 升降与夹爪机构图）**

---

## 9. 待拍 / 待量（不阻塞建模开工）

1. ⚠️ **Z 轴约束方式还没拍**：我建议 **"吊式布置 + 竖直短导轨"**（DS3225 只当推杆，连杆不兼导向），替代"纯吊式平行四边形连杆"——理由与算式见 `Claude接续日志.md` 2026-09-16 那一轮讨论。
2. **参考件的齿数/模数**：在 Fusion 打开 `参考\SO-ARM夹爪\models\RB9.01.062.000 Gripper.STEP` 实量（我方设计不依赖它，但量一眼能验证上面 M1.5/z14 的取舍是否合理）。
3. 盒内腔/托盘最终尺寸以建模为准 → 若有变动，回来核对 **§0 的"开口 64 / 行程 56 / 总高 82"** 是否需要微调（重跑 `gripper_design.py` 即知）。

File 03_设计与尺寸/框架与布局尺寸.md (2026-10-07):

# 框架与布局尺寸（龙门 XYZ · 40×40 铝型材 · 350×350）

> 2026-09-17 定稿。配套《夹爪设计参数表.md》使用。
> **这是三维建模与第三批采购的依据**；建模工具是 MayCAD（铝型材）+ Fusion（打印件/总装）。
> 改完框架用 `python maycad_check.py <你的>.scene` 自校（或把 .scene 发我）。

**一句话**：40×40 铝型材搭 350×350 的龙门框架，**立柱落地 260mm**，顶框 270×270 平齐，**导轨梁 2×350 沿深向架在顶框上面**，Y 梁吊在导轨梁下；托盘（外廓 160）在前、**2×3 储物盒组（盒外宽 86）**在后，全部进 350×350×450。

---

## 1. 坐标系与外廓

- 宽 = X（左右）、深 = Y（前后，前=0）、高 = Z（离地）。地面 = Z0。
- **整机外廓：350 × 350 × 300mm**（宽×深×高），距规则上限 450 还有 150mm 余量（给屏幕/线槽/相机支架）。

## 2. 高度尺寸链（立柱为什么是 260）

> ⚠️ **2026-09-17 下午修正（重要，切型材前必读）**：下面的链条里"**夹爪高 26**"是**错的** —— 26 只算了主框，没算两根齿条 + 齿轮 + 舵机。按 `夹爪\gripper_design.py` 参数化算出的**夹爪真实包络 = 82mm 高**（爪板 48 + 传动 30 + 框顶 4；换布局最少也要 ~70）。
> 于是 **Y 梁底面要抬到离地 ≈250 → 立柱顶 ≈310 → 整机 ≈350**（规则上限 450 仍 ✅，余 100）。**即立柱要从 260 加长到 ~310**。
> 详见 `夹爪\夹爪校核报告.txt` 与 `夹爪\用法.md` §4。**改完 MayCAD 场景后务必重跑 `python maycad_check.py <场景>.scene` 复核。**

| 段 | 高度（离地 mm） | 依据 |
|---|---|---|
| 底框（4040） | 0 ~ 40 | |
| 底板（5mm，坐底框上） | 40 ~ 45 | **工作台面 = 45** |
| 储物盒口（内腔 45 + 底 3） | 台面上 48 | 4 件 ≤40mm 货 2×2 单层 |
| **夹爪高位爪底** | **台面上 68（离地 113）** | 盒口 48 + 抬升余量 20（横移不刮盒沿） |
| + 夹爪高 26 + 转接板 10 + 滑块 45 | +81 | |
| = **Y 梁底面** | **离地 194（台面上 149）** | ← 这是硬指标，校核按 **≥150** |
| + Y 梁 40 + 滑块/连接 20 | +60 | 下挂式叠法 |
| = **导轨梁底面 / 立柱顶面** | **离地 254** | |
| + 导轨梁（4040） | 254 ~ 294 | 架在顶框上面 |
| **整机顶** | **≈ 300** | ✅ ≤450 |

**立柱长 = 254 − 立柱脚底高度**：立柱落地（脚底 Z0）→ **立柱 = 255~260mm**（取 260，含 6mm 余量）。

> ⚠️ 若立柱改站底板/底框上，立柱长度要相应减（站底板 45 → 立柱 215；站底框顶 40 → 立柱 220）。**不变量是"Y 梁底面距台面 ≥150"，不是立柱长度本身。**
> 敏感性：盒内腔每 ±10mm → 立柱 ±10mm。夹爪高、滑块长同增减。底板/底框厚度只抬整机、不改立柱长（立柱落地时除外）。

## 3. 下料表（4040，共 ≈4.2m，买 4.5m）

| 件 | 长 (mm) | 数量 | 位置 |
|---|---|---|---|
| 立柱 | **260** | 4 | 四角，落地 |
| 底框横梁 | 270 | 4 | 贴地一圈（0~40） |
| 顶框横梁 | 270 | 4 | 220~260，顶面与立柱平齐 |
| **导轨梁（深向）** | **350** | 2 | **顶框上面（260~300），架左右立柱顶面** |
| Y 梁（宽向） | 270 | 1 | 吊在两根导轨梁下面（底面离地 200） |

连接：端面攻丝 M8 + 中心连接件（沿用你现在 MayCAD 里的 CT_THREAD_TO_SLOT / CONN40-40_CENTRAL_UNIVERSAL）。角件/T 螺母若干。

> ⚠️ 采购清单 H1 现在是"2020 等，60~100 元"。定了 4040 要改：4040L 按 20~25 元/m，4.5m ≈ **90~110 元**，外加角件/连接件。

## 4. 龙门机构与行程预算

| 轴 | 导轨/梁 | 行程 | 需要 | 余量 |
|---|---|---|---|---|
| **深向（Y 梁随导轨移动）** | **2×350 导轨梁** | 350 − 滑块 45 = **305** | **~289**（托盘前沿货 y≈10 → 后排盒心 y≈299；加两端余量 ~12 → ~301） | ✅ **4~16**（盒外宽 86 定稿后已不再是最紧轴） |
| 宽向（夹爪随 Y 梁移动） | Y 梁 270 | 270 − 45 = **225** | ~176 | ✅ 49 |
| Z（竖直） | 竖直导轨 115~125 | 行程 **70** | 65（台面触底→高出盒口 20） | ✅ |

> ⚠️ **新发现的次紧点：深向"前探"**（`layout_check.py` 校核发现）。滑块不悬出时夹爪中心最前只能到 y=22.5，而托盘前沿小件中心在 y≈10 → **托盘前部 ~12.5mm 条带够不着**（注：40mm 大件放最前时中心在 y≈24.5，**本身够得着**；受影响的是小件贴着托盘前沿摆的情况）。**补救（推荐 ① 或 ②）**：
> 1. **深向滑块前端允许悬出 ~14mm** —— **MGN 线轨可以**（滚珠自带保持）；⚠️ **光轴+LM8UU 绝对不行**（滚珠会掉）→ 深向本来就该用 MGN，见下；
> 2. **夹爪相对滑块前移安装 ~15mm**（**推荐**：只改转接板孔位，不动导轨、不影响后行程）；
> 3. 深向滑块**换短款 MGN12C（35mm）** → 最前 y=17.5，缓解 5mm（可与 ①②叠加）；
> 4. ~~托盘整体后移~~ → **只能后移 ~6mm（吃掉托盘/盒组那道缝），再多盒组后沿会顶出 350**（342+15=357 ❌）。仅作缓解，不能根治。
>
> **建模时按 ①/② 定一条。**

以下为历史存档（盒外宽 88 口径时深向差 1mm 的补救项，现口径下已不必须，留作后备）：

1. **深向滑块用短款 MGN12C**（~35mm）→ 行程 315；
2. **深向用 MGN 线轨、允许滑块端部悬出 ~10mm**（滚珠自带保持，可行）——⚠️ **光轴+LM8UU 不行**，轴套滑出光轴端滚珠会掉，所以**深向别用光轴**（宽向行程富余，可用光轴）；
3. **储物盒做成一体 2×3 盒组**（规则允许"可组合可整体"），省掉盒间缝、还能压紧布局。

## 5. 工作区布局（宽 X × 深 Y，单位 mm，前=0）

> **定稿口径（2026-09-17 上午）：盒外宽 86（不是 88）、托盘外廓 160。** 以下坐标与 `layout_check.py` 输出一致，改布局先改脚本常量重跑。

| 件 | 宽 X | 深 Y | 说明 |
|---|---|---|---|
| 托盘（外廓 160，壁 2.5） | 95 ~ 255（居中） | 2 ~ 162 | 规则：≥160×160、边高 ≥10。⚠️ 160 贴下限，**建议建模 162~165 抗打印收缩**（改 `TRAY_OUT` 重跑校核） |
| 储物盒 ×6（外宽 86 / 内腔 82 / 壁 2，节距 88，盒组 262×174） | 44 ~ 306 | 168 ~ 342 | 腔 82 ≥ 4 件 40mm 所需 80（余 2）；可单体固定到底板或一体打印 |

- 宽度：盒组 262 ≤ 内净宽 270 ✅（两侧各余 4）
- 深度：盒组后沿 342 ≤ 350 ✅（余 8）；托盘/盒组之间缝 6
- 取放点（盒腔中心）：前排 (87/175/263, 211)、后排 (87/175/263, 299)；深向需求 y10→299 = 289 ≤ 行程 305 ✅，宽向需求 x87→263 = 176 ≤ 225 ✅
- **盒内腔 ≥82 是红线**（要完全容纳 4 件 ≤40mm 货；装不下取消资格）。**建模按 83 画**留 1mm 打印收缩余量；⚠️ 盒外宽别做 88（宽度余量只剩 2、深向需求涨回 ~311 ❌）。4040 立柱下 86 已是盒外宽上限；**想更宽松就把立柱/底框换 3030**（内净宽 290）。

### 5.1 入盒传感器怎么"留口"（2026-09-17 定，建模时必须做进盒体）

**结论：不在内壁开大开口，做「外侧凸台腔 + 内壁 Ø3 透光小孔」。** 三个硬要求：

| 要求 | 做法 | 为什么 |
|---|---|---|
| **传感器腔做在盒体外侧** | 盒壁外侧局部加厚 **6~8mm** 挖腔，装红外对射的发射/接收管（3~5 元/对，见《采购清单》D1） | 爪子下潜外廓 **71** 对盒内腔 **82**，单侧只剩 **5.5mm** → 传感器塞不进内腔；且**内腔底面必须平整**（4 件 40mm 货 2×2 才放得平） |
| **内壁只留 Ø3~4 透光小孔 ×2** | 对射一对孔**同轴对穿**左右壁，位置在**盒底上方 5~10mm**；孔做成 **Ø3×4 深的小通道**（不是薄壁上的一个洞） | 孔小不影响存料、不漏料；通道形（孔深 ≥4）能挡斜射杂光 |
| **相邻盒防串光** | ① 左右相邻两格传感器高度**错开**（一路离底 6、一路 10），或 ② **最稳：MCU 分时扫描**——轮流点亮 6 路发射管、只读当前那一路（零硬件成本，推荐） | 一格的发射管会照到邻格的接收管 → 不处理会 6 路一起乱跳 |

> ⚠️ **采样时机**：入盒确认必须在**爪子抬起、离开该盒口之后**再读（爪子本身会遮住光路）→ 状态机里把"入盒确认"排在"Z 抬升 + 横移离开"之后。
> **备选（若改用微动/轻触开关）**：同样做在**盒底外侧凹腔**，只让杠杆片伸进内腔 1~2mm；但要先确认**货重 20~50g 能否压下**（普通微动 50~150gf 可能压不动），否则内腔底面会被杠杆顶得不平。
> **零硬件方案（可选）**：若相机最终装在龙门横梁上（能移到盒子上方俯视），可用"移到盒上 → 拍照看格内是否有货"做复核，省掉 6 路传感器，代价是每件多 ~0.5~1s。

## 6. 底板（避开落地的立柱）

立柱落地占着四个角，底板二选一：

| 方案 | 尺寸 | 说明 |
|---|---|---|
| A | **270×350×5~8** | 卡左右立柱之间、深向铺满；前后各悬出 40（前沿会略软） |
| B | 350×350×5~8，**四角开 40×40 缺口** | 绕开立柱、铺满底框 |

不管哪种：**底框中间加一根横梁**托住底板中央（否则放 6 盒 + 抓取下压会塌/翘）。

## 7. 建模顺序与校核工作流

**顺序**：
1. 框架（立柱 260 + 底框 + 顶框 + 2×350 导轨梁 + Y 梁）——MayCAD
2. 底板 + 盒组 + 托盘（Fusion 打印件）—— 摆进框架做**干涉校核**，**重点量深向行程**。布局坐标先跑 `python layout_check.py` 核对（输出《布局校核报告.txt》，含逐点行程覆盖表）
3. Y 梁滑台 + Z 模块 + 夹爪（尺寸照《夹爪设计参数表.md》）——Fusion
4. 量三件事：① 总高 ≈300 ≤450 ② 夹爪低位能触底、高位离盒口 ≥20 ③ 深向行程覆盖全部取放点
5. 说明书第 8 节 4 张附图（整机总装 / 龙门传动 / Z 轴夹爪 / 电源电控布置）从总装出

**自校工作流**：MayCAD 里改完 → `文件→导出 .scene` → 跑 `python maycad_check.py <文件>.scene` → 看【红线校核】清单（外廓/总高/立柱顶/导轨行程/Y 梁净空）。**或直接发我，我跑给你看。**

## 8. 风险与对策

| 风险 | 对策 |
|---|---|
| 深向行程差 1mm 不够 | **已化解**（盒外宽 86 后需求降到 ~289，余 16）；后备补救见第 4 节存档 |
| **深向前探差 ~12.5mm**（托盘前沿小件够不着） | 第 4 节⚠️条：滑块前端悬出 ~14mm（仅 MGN 线轨）／夹爪前移安装／托盘后移 15，**建模时三选一** |
| 托盘外廓 160 贴规则下限，打印收缩即违规 | 建模按 162~165（深度余量 8mm 付得起）；出厂前用卡尺实测 |
| 盒内腔 82 余量小（打印收缩/装配误差） | 内腔按 83 建模留 1mm 收缩余量；仍紧就把立柱换 3030 |
| 底板前沿悬出 40 发软 | 加中间横梁；或底板用 8mm 玻纤板 |
| 立柱 260 锯错 | **先只切 4 根立柱装配实测高度**，对上"立柱顶离地 ≈254~260"再切其余 |
| 规则 450 是整体外廓 | 屏幕/线槽/相机支架都算上，顶部留 20~30mm 余量，别做满 |

---

## 附：为什么这么定（一页速览）

- **350×350 立柱在四角**：托盘 + 6 盒要占 ~262×340，小一号就装不下，所以长宽必须顶满。
- **高度不做满**：高度由 Z 行程链决定（≈300），做满只会让悬臂更长、晃动更大、节拍更慢，而"掉落=本轮结束"。
- **立柱落地 + 顶框平齐 + 导轨梁加一层**：立柱顶 254~260 是为了让吊在导轨下的 Y 梁底面有 150mm 净空，夹爪才能抬着货越过盒沿。
- **导轨梁必须 350 全长**：顶框那 4 根 270 是结构件不是导轨——270 导轨行程只有 225，够不着后排盒子和托盘前沿。

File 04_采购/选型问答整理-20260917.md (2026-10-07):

# 硬件选型问答整理（2026-09-17 晚 · 队内）

> **这份是什么**：把这一轮"边看淘宝链接边定规格"的问答结论整理成一份可传阅的文档 —— 每个问题 = 一节，结论 + 为什么 + 下单参数。
> **配套文档**：《采购清单.md》（下单依据）、《框架与布局尺寸.md》（尺寸依据）、《夹爪设计参数表.md》。
> ⚠️ **队内资料**：竞赛提交件必须匿名，这份不要整份放进校选/省赛提交材料。

## 0. 索引：这轮定了什么

| # | 问题 | 一句话结论 |
|---|---|---|
| 1 | 那块裸 LED 环形灯板能用吗 | 能用，但必须**加乳白罩**；**24V 版和 6S 电池不匹配**，优先换 12V 版 |
| 2 | 同步带选 6mm 还是 10mm | 都不是重点 —— 选 **GT2 / 2mm 齿距 / PU 钢丝 / 6mm**，买 **3 米** |
| 3 | MGN12 线轨买什么参数 | **MGN12 350mm 标准轨 ×2 + MGN12C 短滑块 ×4**，轴承钢、含滑块 |
| 4 | 宽向（X）用什么 | 建议**也上 MGN12C 线轨**（270mm×2 + C×4）；坚持光轴则两根平行、不许悬出 |
| 5 | 角码要几个 | 结构 **22 个**，**买 30 个**；必须装槽内侧 |
| 6 | 电缆/硅胶线买多长 | TRVV **2 卷 20m**；硅胶线 **18AWG 各 6m + 22AWG 各 8m（28m）** |
| 7 | 储物盒怎么放 | **3 列 × 2 排**放底板后部，盒组 **262×174**（逐格坐标见 §7） |
| 8 | 入盒检测要几个传感器 | **6 路 = 6 对红外对射（+2 对备）** |
| 9 | 采购清单 9 条批注 | 逐条解答见 §9 |

---

## 1. 补光灯（采购清单 B3）

### 结论
那块裸 LED 环形灯板（5730 ×24、板载限流电阻）**可以用，但要补三样**：乳白漫射罩、独立一路供电、先确认电压。

### 三个必须处理的坑

| 问题 | 后果 | 做法 |
|---|---|---|
| 裸 LED 直射（无罩） | 货面出现**镜面光斑和多影** → 颜色阈值、"污渍/缺陷"判据误判 | **2mm 乳白 PC/亚克力罩，离灯板 10~20mm**（这条不是可选项）。环径别太小，越靠近镜头反光越正对相机 |
| 和舵机共用一路电 | 舵机堵转瞬间把灯拉暗 → 相机亮度/色偏跳变 | **单独一路降压**；用直流，**不要低频 PWM 调光**（否则画面出条带），要调光就 ≥20kHz |
| 发热 + PLA 支架 | 5~8W 集中在 Ø90 小板上，板面 60~80°C → **PLA 60°C 就蠕变** | 尼龙柱架空 8~10mm，支架离 LED ≥10mm，或用 PETG/ABS |

### ⚠️ 24V 版和我们电源不匹配（重点）

我们电源是 **6S 锂电池**：满电 **25.2V**，放电到 **21V**。

- **24V 定压灯板 + 6S 直通 → 不行**：电压会从 25.2V 掉到 21V，**亮度变化约 25%**，我们"锁曝光 + 定阈值"的方案直接失效。
- **降压模块也稳不出 24V**（输入 21~25.2V，升不到 24V）。
- **首选：买 12V 版**（6S → 降压 12V，最省事最稳）。
- **若已经买了 24V**：用降压模块稳到 **21~22V**（比额定暗一点，但**亮度恒定**才最关键）；或用自动升降压模块稳 24V（贵、体积大）。
- **绝对不要 6S 直通给灯。**

### 装在哪
相机 + 环灯一起装在**托盘正上方朝下**，**Z ≈ 300~320**（Y 梁最高点约 290 之上，净空 70mm+），工作距离 ≈215mm；整机高度还有 100mm 余量（限 450）。

---

## 2. 同步带（采购清单 C4）

### 结论
**GT2 · 齿距 2mm · PU 钢丝（聚氨酯内嵌钢丝）· 带宽 6mm · 买 3 米**（3 条 1 米）。
同步轮配套：**GT2 20 齿 / 内孔 5mm / 带宽 6mm ×4**。

### 为什么"材质"比"带宽"重要

| 对比 | 橡胶 10mm | **PU 钢丝 6mm** |
|---|---|---|
| 抗拉层 | 页面没写（多半普通纤维） | **钢丝** → 几乎不伸长、不用绷死、长期不蠕变 |
| 宽度够不够 | 够（富余） | **也够**：龙门移动件约 2~2.5kg，峰值拉力仅 ~7N |
| 定位稳定性 | 会拉长，跑久了要重新张紧 | 最好（3D 打印机/CNC 开口带的标准做法） |
| 价格 | 略贵 | 更便宜 |

### 传动方式先定一条

| 方案 | 需要多长 | 说明 |
|---|---|---|
| **A. 皮带当齿条**（开口带两端固定在框架上，电机带轮"爬带"） | 深向 ≈0.5m + 宽向 ≈0.4m ≈ 0.9m | **推荐**：开口带正好能用，不用接环；**不需要张紧轮** |
| B. 闭环 + 张紧轮 | 深向环 ≈840mm + 宽向环 ≈640mm | 闭环要买**成品环带**；**别拿开口带自己接**（接头是硬点，定位误差源） |

### 三个提醒
1. **齿距必须和同步轮同规格**（我们是 GT2 = 2mm 圆弧齿）；下单前问客服"是不是 GT2、齿距 2mm"。
2. 页面里**"高品质防滑质量"那档是输送/防滑带**，不是齿形传动带，不要选。
3. 问一句**内部有没有钢丝/玻纤抗拉层**。
4. **硬规矩：拖链里任何一根线都不许有中间接头。**

---

## 3. 深向（Y）MGN12 线轨（采购清单 C5）

### 为什么必须用线轨
深向行程 **350 导轨 − 滑块长 = 需 ≥289**，前探还要允许滑块端部悬出 → **光轴 + LM8UU 悬出会掉滚珠，绝对不行**。

### 下单参数（照着搜）

| 参数 | 选定 | 说明 |
|---|---|---|
| 系列 | **MGN12** | 别买 MGN9（太细）、MGW12（宽法兰、孔距不同） |
| 长度 | **350mm × 2** | MGN12 **标准长度**（孔距 25mm：12.5+13×25+12.5=350），别点"任意切割" |
| 滑块 | **MGN12C × 4**（短款 ≈30mm） | 见下 |
| 材质/等级 | **轴承钢、普通级（普通预压）** | 室内不用不锈钢/精密级 |
| 必确认 | **含滑块** | 有的链接只卖轨 |
| 行情 | 2 轨 + 4 滑块 **≈¥100~160** | 原估 130~200 偏保守 |
| 搜索词 | `MGN12 直线导轨 350mm` / `微型直线导轨 MGN12C 含滑块` | ⚠️ **"深向"是我们图纸的内部叫法，淘宝没有这个词** |

### 为什么选 MGN12C（短滑块）
我们原文档按 **H 型（≈45mm）** 算，得出"前探差 12.5mm"（托盘最前面的小件够不着）。

- 换 **C 型（≈30mm）**：滑块中心能往前多走 ≈15mm → **前探差从 12.5mm 缩到约 5mm**（再配"夹爪前移 5~10mm"即彻底解决）；
- 深向行程变成 350 − 30 = **320mm**（需 289）→ 余量从 16 涨到 31。
- 代价：短滑块抗倾覆力矩略小 —— 但每条轨 2 个滑块（共 4 个），足够。

### ⚠️ 安装要加转接板
MGN12 是 **M3 孔**（孔距 20/25mm），而 4040 型材槽是 8mm（配 M8 T 螺母）→ **需要一块 5mm 铝板/扁铁过渡**（M5 T 螺母固定到型材槽，导轨锁在板上），顺便得到平整基准面。

---

## 4. 宽向（X）用什么（采购清单 C6）

⚠️ **"宽向"也是内部叫法**（= 左右方向 = X 轴），淘宝搜不到。若继续用光轴，搜：`Ø8 光轴 加硬` / `LM8UU 直线轴承` / `SK8 光轴支撑座`。

| 方案 | 规格 | 估价 | 评价 |
|---|---|---|---|
| **改 MGN12C 线轨（推荐）** | 轨 270mm × 2 + C 滑块 × 4 | ¥70~110 | 与深向同规格同批买省运费；抗"吊着 Z 轴+夹爪"的偏心力矩好；无 LM8UU 旷量与掉珠风险（同样要转接板） |
| 沿用光轴 | **两根平行 Ø8** + 每根 2 个 LM8UU + 4 个 SK8 支撑座 | ¥50~80 | **两条铁律：两根平行；轴端绝不许悬出**（LM8UU 滑出会掉珠） |

---

## 5. 角码 / 连接件（对应待办 H1b）

### 结论
**结构上需要 22 个，买 30 个**（含附件支架 8 个），约 ¥30~45。

| 位置 | 接头数 |
|---|---|
| 底框 4 根 270 梁 × 两端 | 8 |
| 顶框 4 根 270 梁 × 两端 | 8 |
| 底框中横梁（撑底板那条）× 两端 | 2 |
| 2 根 350 导轨梁搭在立柱顶面 × 两端 | 4 |
| 导轨梁与顶框梁贴合面 / Y 梁吊装 | 0（用 T 螺母 / MGN 滑块） |
| **小计** | **22** |

### 两条注意
1. ⚠️ **必须买"能装在槽内侧"的角件，并全部装在内侧** —— 外廓正好卡在规则上限 350×350，外贴式角件会让外廓变 ~355（违规）。
2. **角码和"端面攻丝 + 中心连接件"是配套，不是二选一**：中心连接件抗拉压好但**抗扭差**，角码正好补抗扭。

| 方案 | 每个接头 | 总数 |
|---|---|---|
| **中心连接件 + 角码（推荐）** | 1 + 1 | 22 个角码 + 22 个中心连接件 |
| 全靠角码 | 2 | 44 个（买 50） |

配套：**M8 丝锥 ×1**、**M8 T 螺母 + 内六角螺栓 50~60 套**；规格要 **4040 专用角件（腿长 30~40）**。

---

## 6. 电缆与硅胶线（采购清单 G1 / G2）

### TRVV 拖链电缆：**买 2 卷 20 米**
4芯 × 0.5mm² × 10m ＋ 6芯 × 0.2mm² × 10m（6 芯若只有 0.3mm² 也行）。

| 卷 | 剪成几段 | 用途 |
|---|---|---|
| 4芯 × 0.5 | X 电机 1.8m ＋ Y 电机 1.8m | 步进电机（电机装在横梁端头，只穿 Y 拖链） |
| 6芯 × 0.2 | 拖链内信号 2.5m（触货微动 2 + Z 限位 2 + X 限位 2）；Y 原点限位 1.0m；串口屏＋按钮/急停/蜂鸣器 1.2m；6 路对射 2m＋2m | 信号 |

- **长度由走线路径决定，跟几根芯无关**：拖链里"必须一根连续"的最长一段 = **2.5m**（Z 滑座上那束）。
- **省线优化**：6 路对射**共用 VCC/GND 母线**，只留 6 根信号 → 总根数从 18 降到 8。
- **硬规矩：拖链里不许有中间接头**（接头在反复弯折处必断）。

### 硅胶导线：**买 28 米**（约 ¥50~60）
18AWG 红黑各 **6m** ＋ 22AWG 红黑各 **8m**。

| 规格 | 用途 |
|---|---|
| **18AWG（0.75mm²）** | 电池 → 总开关 → 保险丝 → 分电；分电 → 2 个驱动器 / 2 个降压；**舵机电源（穿拖链 2.5m 那对）**；低压报警 |
| **22AWG（0.3mm²）** | 舵机**信号** 2 根；5V 分支配电（主控/屏）；启动、急停、蜂鸣器；备用 |

- ⚠️ **舵机电源不能走 TRVV 8 芯 × 0.3mm²**：0.3mm² 约 55mΩ/m，往返 5m，堵转 3A 时**压降 ≈0.8V**，线束发热也不好 → 电源单独走 18AWG 一对，TRVV 只走信号。
- ⚠️ **店家按 2 米一档卖**：需求每色 4.8m / 7m → 买 **18AWG 各 3 档、22AWG 各 4 档**。**单根 2m 不够拖链那根 2.5m**，让店家**发一整根 4 米**，或把降压模块挪到拖链起点（动段缩到 ~1.6m）。
- 一个舵机的 3 根线**套网管捆成一束**再进拖链，别散着走。
- **USB 摄像头线**：1.5~2m 带屏蔽（别超 3m，2K MJPEG 会掉帧）。
- **小型拖链**（内腔 10×15 或 10×20）：Y 向 ~0.6m + X 向 ~0.45m。

---

## 7. 储物盒放置

### 结论
**3 列 × 2 排，放在底板后部，托盘在前**；盒组 **262 × 174**（外宽 86 / 内腔 82 / 壁 2 / 节距 88），居中放置。

### 逐格坐标（单位 mm，前 = 0）

| 盒号 | X 范围 | Y 范围 | 腔中心（取放点） |
|---|---|---|---|
| 1（前排左） | 44 ~ 130 | 168 ~ 254 | (87, 211) |
| 2（前排中） | 132 ~ 218 | 168 ~ 254 | (175, 211) |
| 3（前排右） | 220 ~ 306 | 168 ~ 254 | (263, 211) |
| 4（后排左） | 44 ~ 130 | 256 ~ 342 | (87, 299) |
| 5（后排中） | 132 ~ 218 | 256 ~ 342 | (175, 299) |
| 6（后排右） | 220 ~ 306 | 256 ~ 342 | (263, 299) |

托盘在前：X 95~255 / Y 2~162，与盒组留 6mm 缝。

### 为什么必须是"3 列 × 2 排"
宽度 270 能放下 3×86 + 2×2 = 262；深向放不下 3 排（托盘 162 + 缝 6 + 3 排 262 = 430 > 350）。**排数只能 2、列数只能 3**，没有第二种摆法。

### 怎么固定 / 怎么分件打印
- ⚠️ **整块 262×174 打不出来**（打印机幅面 ≥200mm）→ 推荐打 **3 条"2 格条"= 86×174×48**，再用 2mm 垫片/定位凸台并成 262；或打 6 个单体 86×86×48。
- 整体 **4 颗 M3**（前后各 2）+ 2 个定位凸台固定到底板；**不要粘死**（决赛要现场换手爪、清盒）。
- **底框中间那根横梁必须装**（托住底板中央），否则 6 盒 + 抓取下压会塌/翘。

### 建模时必须一起做进去的 4 件事
1. **内腔 82**（红线：要完全容纳 4 件 ≤40mm 货），**按 83 画**留收缩余量；⚠️ 盒外宽**别做 88**。
2. **盒口 2~3mm×45° 导角**（喇叭口），落货容错。
3. **内腔底打细网格纹**（打印直接成型）—— 防滑又不挡对射光路。⚠️ 别贴 6mm 厚橡胶垫（会永久挡死光路）。
4. **传感器留口**：盒壁**外侧**局部加厚 6~8mm 挖腔 + 内壁 **Ø3×4 同轴透光孔 ×2**（离盒底 5~10mm）。

### 三条硬约束
| 约束 | 数值 | 超了会怎样 |
|---|---|---|
| 盒组宽 ≤ 内净宽 | 262 ≤ 270（两侧各余 4） | 顶到立柱装不下 |
| 盒组后沿 | 342 ≤ 350（余 8） | 整机超 350 → 违规 |
| 盒口高 | 台面上 48（内腔 45 + 底 3） | 低于此值，夹爪抓着货过不了盒沿 |

### 编号
面向机器前方，前排左→右 = 1/2/3，后排 = 4/5/6，盒口外侧贴标签。**但哪个盒放哪类货由程序动态分配**（规则"同形同色归同盒"，编号只给人看）。

---

## 8. 入盒检测传感器（采购清单 D1）

### 结论
**6 路**（6 个盒子每格一路）。每路是**一对红外对射（1 发 + 1 收）** → **买 6 对、备 2 对 = 8 对（16 个管子）**，约 ¥20~45。

| 计数口径 | 数量 |
|---|---|
| 检测路数（= 盒数） | **6** |
| 对射"对"数 | **6**（+2 备） |
| 管子个数 | 12（+4 备） |
| 若买 LM393 模块 | 6 个（+2 备） |

⚠️ **必须买"对射式（发射/接收分体）"，不要漫反射一体式**：漫反射靠货的反光，黑色/深色/带污渍的货反光差会漏检；对射只看光有没有被挡，**与颜色、反射率无关**，跨距 82mm 足够。

### 怎么检测（信号链 + 4 条规矩）
发射管发光 → 横穿内腔 82mm → 接收管收到 → LM393 输出数字电平；**有货挡光 → 翻转 → STM32 读到一个 GPIO**。每路 3 根线（VCC/GND/OUT），供电 3.3~5V。

| # | 规矩 | 为什么 |
|---|---|---|
| 1 | 探头装**盒壁外侧凸台腔**，只留 **Ø3×4 深孔**朝自己格内 | 防串光的**第一道（几何挡光）**；"高度错开"作用有限（邻格光只偏 ~2.6°，深孔照样收得到） |
| 2 | **分时扫描兜底（推荐）**：轮流点亮 6 路发射管、只读当前那路 | ⚠️ 要求 **6 个发射管能单独控制**（各占 1 个 GPIO 或 6 个小三极管）。**只在接收端轮流读没用**，邻格串光照样进 |
| 3 | **采样必须在爪子抬起、离开盒口之后** | 爪子本身会遮光路 |
| 4 | 连续读 3 次（间隔 10~20ms）一致才算 | 货落下会弹，防空判 |

### 一句要紧的话
单束只能判"**格里有东西**"；规则里的"**必须完全进入才计分**"**传感器判不了**（想在 42~44mm 再加一束判"突出"，但货高 40、内腔 45，窗口仅 5mm）→ **靠下放动作保证**（爪子下到接近盒底再松爪、抬起离开）。

### 备选
- **微动开关（D2）：先不买**，等对射装好实测；真要买必须选 **≤30gf** 并用真货试压（货只有 20~50g）。
- **相机复核入盒（D3）：作废** —— 相机固定在托盘上方，看不到后排盒底（y 342）。

### 整机传感器总清单
| 用途 | 数量 | 形式 |
|---|---|---|
| 入盒检测 | **6 路** | 红外对射 6 对（+2 备） |
| 抓到货没有（触货） | 1 | 微动开关（浮动爪顶退 1.5~2mm 触发） |
| X / Y 轴原点 | 2 | 微动开关 |
| Z 高位 / 低位 | 2 | 微动开关 |
| 识别（颜色/形状/文字/二维码） | 1 | USB 2K + 3.6mm 低畸变相机 |
| 相机补光 | 1 | 环形灯 + 乳白罩 + 独立降压 |

---

## 9. 采购清单批注逐条解答

（批注挂在表格的具体行上，下面按行回答。）

| 批注 | 挂在哪 | 回答 |
|---|---|---|
| 「需要买带灯罩，24v 的」 | B3 补光灯 | 灯罩必须要；**但 24V 与 6S 不匹配**（详见 §1），优先换 **12V 版**，或稳到 21~22V |
| 「都有什么？」 | C4 张紧轮套装 | 一般含惰轮+支架+螺栓。**我们走"皮带当齿条"，不需要张紧轮** → 改成"同步轮 + 皮带夹"，张紧靠电机座腰形孔 |
| 「具体参数不清楚」 | C5 深向线轨 | 见 §3 参数表 |
| 「未找到宽向」 | C6 | "宽向"是内部叫法（= 左右方向）。搜索词与建议见 §4 |
| 「c4 不是买了吗？」 | C7 | **C4 与 C7 本来就是同一批东西，应合并成一行**；且**"联轴器"删掉**（同步带传动不需要联轴器） |
| 「买这个何意味？」 | C8 微动开关 | ① X/Y 原点回零（步进开环，没它无法定位）② 夹爪触货（替代"只用延时"）③ Z 低位保护（防撞盒底）。备 4 个便于现场更换 |
| 「没看懂」 | C9 夹爪增补件 | MF106ZZ=导杆滚动支撑；Ø6 导杆×4=两指导向；压簧=恒力夹取（5N）；爪垫=增摩擦护货（建议自打印 TPU 1.5mm）；M1.5 成品齿条=打印齿隙大时兜底 |
| 「已完成」 | E1 串口屏 | 收到 ✅ 提醒：须是**淘晶驰 USART HMI 类**（别裸 TFT），预留 5V/1A |
| 「买多长？」 | G2 硅胶导线 | 见 §6：18AWG 红黑各 6m ＋ 22AWG 红黑各 8m = **28m** |

### 红色但没批注的两行
- **C5 / C6**：按 §3 / §4 处理。
- **D2（微动兜底）先不买；D3（相机复核）作废。**

### ⚠️ 绿色（已买）里 3 个必须回头核对的

| 行 | 核对什么 | 不对的后果 |
|---|---|---|
| **C2 舵机** | **是不是 270° 版** | 180° 版 → 夹爪要改齿轮 M1.5-z16、本体高变 30，脚本/图纸全要重出 |
| **B1 摄像头** | 是不是 **3.6mm 低畸变**、**能锁手动曝光** | 2.8mm 广角 → 小二维码在临界（2.6 px/模块）；不能锁曝光 → 阈值会漂 |
| **D1 对射** | 必须是**对射式（发射/接收分体）**、数量 6 对 | 漫反射遇黑色/深色货会漏检 |

另：**G1 那 1 卷 TRVV 可能不够**（我们算 2 卷 ~20m）。

---

## 10. 下一步：要落进文档的改动

| 文档 | 改什么 |
|---|---|
| `04_采购\采购清单.md` | C4/C7 **合并**（GT2 PU钢丝 6mm 3 米 + 20 齿/5mm 孔/带宽 6mm 同步轮 ×4 + 皮带夹 ×4，删张紧轮与联轴器）；C5 改 **MGN12C ×4 + 参数 + 转接板**；C6 改 **MGN12C 270×2**；D2 先不买、D3 作废；**G1 改 2 卷**；**G2 改 28m 规格**；B3 改 **12V 版 + 乳白罩 + 独立降压**；补 **H1b（中心连接件 22 + 角码 30 + T 螺母/螺栓 60 套）/ H1c（M8 丝锥）/ H5b（备用耗材）**；C7 明确"**5mm 孔**"；**舵机供电 8V → 6.0~6.8V**（DS3225 标称）。预算重算 |
| `03_设计与尺寸\框架与布局尺寸.md` | §4/§5 深向按 **C 型短滑块（≈30mm）** 复核（前探差 → ~5mm、行程 320）；§5 补 **6 格坐标表 + 分件打印方式**；§5.1 防串光顺序改成"**深孔几何挡光为主、分时扫描兜底**"；§3 下料表改 **310 立柱（≈4.64m）** |
| `03_设计与尺寸\夹爪设计参数表.md` | §5 补：爪垫首选 **自打印 TPU 1.5mm** |

> 校核脚本：`05_工具与校核\layout_check.py`（布局/行程）、`maycad_check.py`（框架）；改布局先改脚本顶部常量再跑。

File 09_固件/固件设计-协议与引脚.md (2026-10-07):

# 固件设计：协议 · 引脚 · 状态机

> **2026-09-21 · 线路 C（本会话）· 状态：待评审（有 6 项待确认，见 §11，其中 §11.1 工具链是硬阻塞）**
> 上位机侧配套文档：`hw_bridge\protocol.md`（桥的用法 + 板子线协议提案 §5）。
> 权威依据：`01_规则与命题\2026年…项目II-2：智能分拣项目命题和比赛规则.pdf`。
> 接口契约（安全责任划分、应答时限）：`Claude接续日志.md`「🔌 分工与交接」。

---

## 0. 一句话定位

STM32F103RCT6 扮演 **"哑执行器 + 安全守门人"**：

- **哑**：只认 §3 的 ASCII 行协议，收到明确命令才动，动完发 `EVT` 回报；不猜意图、不自主决策。
- **守门人**：**一切安全判断（软限位、未回原点禁动、急停）都在固件里**。
  这是与上位机（AI）的硬契约 —— **上位机不做兜底，桥只发字节、不做任何安全判断**。

> 为什么这么分：AI 会犯错（幻觉出越界坐标、把轴名写错、命令发一半）。让"最不可能出错的一层"兜住安全问题，是这套架构唯一站得住的理由。

---

## 1. 边界：做什么 / 不做什么

| | 内容 |
|---|---|
| **做** | ① 线协议收发（USART1 @115200，**已在本板实测可用**）② X/Y 两轴步进点位运动 + 回零 ③ Z 轴舵机升降 ④ 夹爪舵机开合 + 触货确认 ⑤ 6 路入盒检测 ⑥ 串口屏指令代理 ⑦ 急停 / 软限位 / 状态机 ⑧ 蜂鸣器 + 启动按钮 |
| **不做** | ❌ 视觉识别（在上位机）❌ 分拣决策与调度（在上位机）❌ 任何"猜测性"动作：**没收到明确命令就不动** |

---

## 2. 硬件接口清单（来源与确认状态）

| 部件 | 型号 / 规格 | 来源 | 接口形式 | 确认状态 |
|---|---|---|---|---|
| 主控 | **STM32F103RCT6** 最小系统板 | 采购清单 A1，**已到货** | — | ✅ 已实测：高容量 F103（DEV_ID `0x0414`）、bootloader V2.2、板载 CH340K 在 USART1 |
| X/Y 步进 | **自备**（采购清单 C1 注明为"张大头 Emm42 闭环步进套装"） | 已有 | STEP / DIR / EN 脉冲 | ⚠️ **待确认**：是否 Emm42？EN 极性？接口能否 3.3V 直连？（§11.2） |
| Z 轴升降 | **DS3225 270°** 舵机 ×1 | 采购清单 C2，未到货 | 50 Hz PWM | ✅ 形式确定，脉宽标定待做 |
| 夹爪开合 | **DS3225 270°** 舵机 ×1 | 同上 | 50 Hz PWM | ✅ 同上 |
| 原点/限位/触货 | 微动开关 ×8（用 4 备 4） | 采购清单 C8 | 干接点 → GPIO 上拉 | ✅ X 原点、Y 原点、夹爪触货、Z 低位 |
| 入盒检测 | **红外对射对管 + LM393 模块** ×6 | 采购清单 D1 | 数字输出（3.3~5V） | ✅ 方式确定；⚠️ 供电电压影响电平安全（§6、§11.4） |
| 串口屏 | **淘晶驰 3.5″ USART HMI** | 采购清单 E1 | UART（TTL） | ✅ 独立挂在 USART3，由固件代理 |
| 电源 | 6S 锂电 → XL4015（舵机 8V/5A）、LM2596（5V/3.3V） | 已有 | — | ⚠️ 舵机 8V 与 MCU 3.3V **必须共地** |
| 烧录 | ST-Link V2（已有）／ 串口 ISP | 已有 | SWD ／ BOOT0+USART1 | ✅ **串口 ISP 已在 2026-09-21 实测打通** |
| 工具链 | — | — | — | ❌ **本机未安装任何嵌入式工具链**（§11.1 阻塞） |

---

## 3. 线协议规格 v1.0

### 3.1 物理层

| 项 | 值 | 依据 |
|---|---|---|
| 串口 | **USART1**，PA9(TX) / PA10(RX) | 板载 CH340K 就接在这里（bootloader 应答反证，2026-09-21 实测） |
| 参数 | **115200 8N1** | 与桥默认一致 |
| 行尾 | `\n`（兼容 `\r\n`） | |
| 编码 | ASCII | 中文只出现在 `LCD` 透传内容里（UTF-8 或 GBK，随屏） |
| 时限 | **每条命令 ≤100 ms 内必须回一行** | 接口契约第 3 条 |
| 最大行长 | 64 字节（超出丢弃并回 `ERR 10`） | 防缓冲区被灌爆 |

### 3.2 命令表（主机 → 板）

| 命令 | 立即应答 | 完成时异步事件 | 说明 |
|---|---|---|---|
| `PING` | `OK pong` | — | 心跳（桥侧起手第一句） |
| `VER` | `OK fw=0.1.0 proto=1` | — | 版本自描述 |
| `HELP` | `OK commands=PING,VER,STATUS,...` | — | **自描述命令表，方便 AI 自发现**（不靠人记文档） |
| `STATUS` | `OK state=READY homed=XY estop=0 box=101000 pos=1234,567 z=UP grip=OPEN` | — | 一行汇总，字段固定顺序 |
| `GETPOS` | `OK x=1234 y=567 z=1250 grip=900` | — | `z`/`grip` 是舵机脉宽 µs |
| `HOME ALL` | `OK homing` | `EVT HOME_DONE ALL` / `EVT HOME_FAIL <ax> code=16` | 依次 X→Y |
| `HOME X` / `HOME Y` | `OK homing` | 同上 | 单轴回零 |
| `JOG <轴> <步数>` | `OK` | `EVT MOVE_DONE <轴>` | 相对运动，步数带符号，如 `JOG X 200` |
| `MOVE X <步> Y <步>` | `OK` | `EVT MOVE_DONE XY` | 绝对坐标（**未回零一律 `ERR 11`**） |
| `ZUP` / `ZDOWN` | `OK zup` / `OK zdown` | `EVT Z_DONE UP\|DOWN` | 升降到两个标定位（脉宽 2500µs / 500µs） |
| `ZSET <µs>` | `OK set` | — | 直接给舵机脉宽（500~2500，**标定/调试用**） |
| `ZPCT <0~100>` | `OK set` | — | 按行程百分比升降（换机构不用改协议）✅ **M2 实测** |
| `GRIP` | `OK grip` | `EVT GRIP_DONE loaded=0\|1` | 闭爪；`loaded` 由**微动开关**确认触货。⚠️ **M2 未接微动 → 恒报 `loaded=0`（未确认），不是"没夹到"** |
| `RELEASE` | `OK release` | `EVT RELEASE_DONE` | 开爪 |
| `GSET <µs>` / `GPCT <0~100>` | `OK set` | — | 夹爪脉宽 / 百分比（标定用；`GSET` 是 `ZSET` 的夹爪版） |
| `SAFE` | `OK safe z=up grip=open` | — | 显式回安全位（Z 最高 + 夹爪张开） |
| `BOX?` | `OK box=101000` | `EVT BOX_CHANGED box=101000` | 6 路入盒状态（1=有货）。**状态变化会自动推事件**（**20ms 非阻塞采样消抖**，2026-09-22 由 1ms 改，见日志） |
| `MS?` | `OK ms=<n>` | — | 自复位以来的毫秒数。**自证 SysTick 真的在走**（连发两次，差值应≈间隔毫秒）✅ **2026-09-22 实测误差 0.08%** |
| `LCD <内容>` | `OK lcd_sent=<n>B` | — | **原样转发**给串口屏 + **自动补 `FF FF FF`**（淘晶驰每条指令必须以此结尾）。`<n>` = 实际发出字节数（内容长度+3）—— **没接屏时靠它验证载荷有没有被截断、内部空格有没有丢** ✅ 2026-09-22 实测 `LCD page0.t1.txt="A B C"` → `lcd_sent=23B`（20+3） |
| `LCDRAW <hex>` | `OK lcd_raw=<n>` | — | 原样发十六进制字节、**不补** `FF FF FF`（要发二进制/特殊字节时用） |
| `LCDBAUD <1200..921600>` | `OK lcd_baud=<n>` | — | **运行时切屏侧波特率**。⚠️ 淘晶驰出厂常为 **9600**；两边不一致时屏**毫无反应**（不报错、不显示，最难查的一种）→ 用这条现场试，**不用重烧固件** ✅ 2026-09-22 实测 |
| `LCDRD` | `OK lcd_rx=<hex…> count=<n>` | — | 读屏发回来的字节（触摸事件、错误码应答），十六进制 —— **用来判断"屏到底有没有在说话"** ✅ 实测（无屏时 `count=0`） |
| `USART3?` | `OK cr1=… brr=… sr=… crh=… idr=… lcdbaud=…` | — | **屏不动时的第一站**（仿 `TIM3?`）。`idr` 报 **PB10/PB11 的实际电平** —— 空闲时 PB10 必为 1，回环时 PB11 应跟着走；`crh` 应为 `…4B…`（PB10=`0xB` 复用推挽、PB11=`0x4` 浮空） ✅ 实测 |
| `LCDPD <0\|1>` | `OK pb11=pull_down` / `pb11=floating` | — | 把 PB11 切"**下拉输入**"，再看 `USART3?` 的 `idr`：bit11 仍为 **1** ⇒ 有东西在主动驱动它（**屏的 TX 确实接着**）；为 0 ⇒ 那根线没通。**这是排除"浮空输入读到高"假象的客观办法。看完必须 `LCDPD 0` 恢复浮空。** ✅ 实测 |
| `ESTOP` | `OK estop` | `EVT ESTOP reason=cmd` | **立即停**。⚠️ 2026-09-22 实现改为**冻结舵机（不动）**：急停语义是"立刻停住"，此时把 Z 抬起来/张开爪反而是在制造动作。要回安全位请显式发 `SAFE`（或 `CLEAR`） |
| `CLEAR` | `OK cleared` | — | 退出急停/故障；**强制回到"未回零"**，并把舵机送回安全位 |
| `RESET` | （无应答，软复位） | — | 与桥的 `serial_reset(mode="command")` 对齐 |
| `CFG <k> <v>` | `OK` | — | 运行时改参数（速度/加速度/软限位），掉电不保存（v1 从简） |

> 命名取舍说明：**统一用 `轴` 关键字**（`HOME X`、`JOG X 200`）而不是 `HOMEX`/`X200`，是为了让 AI 生成命令时不必记忆多套语法；空格分隔也好人读。
> `GRIP`/`RELEASE` 采纳日志里线路 B 的原提案；`GETPOS` 采纳（并入 `STATUS`）。

### 3.3 应答与错误码

应答统一两种：`OK [payload]` / `ERR <code> [msg]`。

| code | 含义 | 触发场景 |
|---|---|---|
| 1 | 未知命令 | 打错字 —— **不要沉默** |
| 10 | 参数错误 | 轴名非法、步数非数字、行长超限 |
| 11 | **未回原点，拒绝运动** | 上电后直接 `MOVE`（契约第 2 条） |
| 12 | **超出软限位** | 目标或轨迹越界 |
| 13 | 忙 | 正在运动时又来一条运动命令 |
| 14 | 处于急停/故障态 | 必须先 `CLEAR` |
| 15 | 夹爪未触货 | `GRIP` 后微动开关没闭合 |
| 16 | 回零失败/超时 | 找不到原点 |
| 17 | 内部错误 | 兜底 |
| 19 | 屏指令为空 | `LCD` 后面没跟内容 |
| 20 | 屏指令 hex 非法 | `LCDRAW` 的参数含非十六进制字符（或为空） |
| 21 | 屏波特率超范围 | `LCDBAUD` 的参数不在 1200~921600 |

> 说明：**18 号"屏没接"已作废** —— 2026-09-22 串口屏透传已实现（`LCD` 系列），见 §7。

### 3.4 异步事件

格式：`EVT <NAME> [k=v ...]`；自由文本调试信息用 `LOG <text>`。
板子**主动**上报的事件只有两类：① 命令完成/失败 ② **`EVT BOX_CHANGED box=101000`**（入盒状态去抖后发生变化时）。
桥的后台线程会把这些异步行一并缓存，AI 用 `serial_read` 随时取 —— 所以**不需要轮询 `BOX?`**。

### 3.5 为什么"长动作先回 OK、完成再发 EVT"

因为契约要求 **≤100 ms 必须应答**，而"移动到 1234 步"可能要 1~2 秒。先回 `OK` 表示**命令已被接受**（不是"已完成"），完成时用 `EVT` 通知。
→ AI 侧的判据：`OK` = 受理；`EVT *_DONE` = 真的做完了。**这两件事必须分清，否则会写出"以为动完了其实还在走"的 bug。**

---

## 4. 安全状态机

```
        上电
         │
     ┌───▼────┐  外设初始化完成（电机使能=断、舵机回安全位）
     │  INIT  │
     └───┬────┘
         │ 自检通过
     ┌───▼──────────┐  只接受 PING/VER/HELP/STATUS/GETPOS/BOX?/LCD/
     │ IDLE_UNHOMED │  HOME/CLEAR/ESTOP/RESET  ← 运动命令一律 ERR 11
     └───┬──────────┘
         │ HOME ALL / HOME <轴>
     ┌───▼────┐  回零中；再次收到运动命令 → ERR 13
     │ HOMING │  失败 → FAULT
     └───┬────┘
         │ 全部轴回零完成
     ┌───▼────┐
     │ READY  │◀────────────┐
     └───┬────┘             │ 运动完成
         │ 收到运动命令      │
     ┌───▼────┐             │
     │ MOVING │─────────────┘
     └───┬────┘   运动中被 ESTOP/超软限位 → FAULT
         │
   ┌─────▼─────┐   中断源：急停引脚(EXTI) / ESTOP 命令 / 越限 / 看门狗
   │  ESTOP    │   动作：立刻停脉冲、断电机使能、蜂鸣器长鸣
   └─────┬─────┘   只接受 CLEAR / STATUS / PING
         │ CLEAR
   ┌─────▼─────┐
   │   FAULT   │ → CLEAR 后回 IDLE_UNHOMED（**必须重新回零**）
   └───────────┘
```

**三条不可协商的规矩**：

1. **未回零 → 一切运动命令 `ERR 11`**（上电位置是随机的，不回零就没有坐标系）
2. **软限位在固件里夹**：目标越界 `ERR 12`；**运动过程中也要逐拍检查**，不能只在起点判一次
3. **`CLEAR` 之后必须重新回零** —— 急停可能发生在任意位置，位置可信度必须清零

**急停建议双路**（§11.6）：固件 EXTI 检测只是"软急停"；**强烈建议把急停按钮的常闭触点串进步进驱动器的使能/电源回路**，做到断电级硬急停。软件会死、会跑飞、会被看门狗复位，硬件不会。

---

## 5. 运动控制

### 5.1 步进脉冲引擎（软件，一个定时器中断）

- `TIM4` 更新中断 @ **20 kHz**（50 µs 一拍）作为唯一时基。
- 每拍为 X/Y 各算一次：按**梯形速度曲线**（加速度 A / 最高速 Vmax / 减速点）决定本拍是否翻转 STEP 引脚。
- 位置计数在软件里（`int32_t`）；Emm42 闭环电机自己会补丢步，软件计数只作轨迹规划用。
- **不在中断里做任何字符串/串口操作** —— 中断只碰 GPIO 和整数。串口收发全在主循环。

> 为什么不用硬件 PWM 发脉冲：硬件 PWM 换速要重算寄存器、且两轴插补很别扭。软件时基换来的是"想加 Z 轴/插补随时能加"，代价是 20 kHz 下 CPU 占用约 3~5%（72 MHz 完全够）。

### 5.2 舵机

- `TIM3` @ **50 Hz**（20 ms 周期），CH3=PB0（Z 轴）、CH4=PB1（夹爪）。**1 µs 分辨率**（TIM3 计数 1 MHz → ARR=19999）。
- 舵机能力范围：脉宽 **500~2500 µs ↔ 0~270°**（DS3225 **270° 版**；180° 版会把行程减半，采购清单已锁 270°）。
- **Z 轴工作行程 = 600 ~ 2400 µs**（`SERVO_Z_LO/HI_US`，`ZPCT 0..100` 映射到这里）✅ **2026-09-22 实测标定**。
  - 标定结论：装入平行四边形连杆、确认机构跟着动之后，**在 500 µs 与 2500 µs 两端机构都还有余量**
    → **限住 Z 轴行程的是舵机自身的内部机械止挡，不是机构**。
  - 因此两端各留 100 µs（≈13.5°）余量：**长期顶在舵机内部止挡上 = 持续堵转 = 发热，是舵机损坏的头号原因**
    （本项目已经烧掉一颗舵机，见接续日志）。
  - ⚠️ **Z 轴方向（哪端算"最高"）尚未拍板** —— 托盘还没装，看着机构判不出来。
    代码里默认 `ZUP` = 2400 µs；装好托盘后若反了，发 **`ZINV 1`** 即可（运行时生效，不用重烧）。
- 舵机**无位置反馈** → 到位靠**时间 + 微动开关**判断，不靠"以为它转到位了"。
- 上电/急停的安全位：⚠️ **目前一律停中位 1500 µs**。
  - 原来写的是"Z 抬到最高 = 2500 µs"，**实测把机构顶死过**：机构可用行程窄于舵机全域时，
    2500 µs 就是限位；而**打开串口会让板子复位**，于是"每开一次串口就顶一次"。
  - **教训：安全位要选"在任何机构上都安全"的位置，而不是"语义上正确"的位置。**
    等托盘装好、方向拍板后，再把安全位改成真正的"Z 最高 / 夹爪张开"。
- **急停语义已改**：`ESTOP` = **冻结舵机（不动）**，不是"回安全位" —— 急停时去动舵机本身就是在制造动作。
  要回安全位请显式发 `SAFE`（`CLEAR` 也会回）。

### 5.3 回零（Homing）

- 顺序：X 先、Y 后（避免两轴同时撞限位造成机械应力）。
- 流程：向原点方向**低速**走 → 碰到微动开关 → 反向退出一点 → 再低速逼近一次（**二次逼近去抖动**）→ 该点记为零点。
- 硬保护：走超过 **理论行程 × 1.2** 还没碰到开关 → `EVT HOME_FAIL code=16`，进 FAULT。
- 回零完成后写入软限位：`[0, 行程]`，并把当前位置置 0。

---

## 6. 入盒检测（6 路）

规则要求"**货物必须全部进入储物盒才计分**"，所以这一路是**计分依据**，不是装饰。

- 6 路红外对射，接收端接 `PC0~PC5`，内部上拉，**低电平 = 有货挡光**。
- **去抖**：连续 N 次（建议 5 ms × 4 = 20 ms）读到同一状态才认账，再发 `EVT BOX_CHANGED`。
- ⚠️ **采样时机**：必须在**爪子抬起、离开盒口之后**再采 —— 爪子本身会挡光（这条来自 `03_设计与尺寸\框架与布局尺寸.md` §5.1 的定稿口径）。
- ⚠️ **防串光 = 分时扫描**（推荐）：逐个点亮发射管、只读对应那一路。这需要**每路发射管可单独控制**（6 个 GPIO 或 1 片 74HC138 译码），是 §11.3 的待确认项。
- 兜底：即使做了分时扫描，规则里"未全入盒不计数"代价很高，建议保留 **D3 的"俯视相机复核"** 作软件冗余（AI 侧用 `cam_shot` 看一眼柜格）。

---

## 7. 串口屏代理（✅ 2026-09-22 已实现，fw 0.2.3）

- 屏挂在 **USART3**（`PB10`=TX / `PB11`=RX），与 PC 侧无关。
- 固件提供 `LCD <内容>` **原样透传**，不解释协议 —— 因为淘晶驰的指令集是它自己的方言，让上位机（AI）直接写屏指令最灵活，**改屏的界面一行固件都不用动**。
- 典型用法：AI 发 `LCD page 1` / `LCD t0.txt="第3件：红色方块"`，屏自己显示。
- **`LCD` 会自动补 `FF FF FF`**（淘晶驰每条指令必须以此结尾才会被执行）；要发裸字节用 `LCDRAW <hex>`。
- **波特率**：⚠️ **本屏（TJC4832T135_011R）实测出厂就是 9600**，固件默认值也已是 **9600**（`board.c` 的 `lcd_init(9600u)`）。
  **波特率不对时屏"完全不响应"** —— 它收到的是乱码、不会解析、**一个字节都不回**，而屏幕上毫无异常表现；
  ⚠️ 反直觉的地方：这时**接收端也是 0 字节**（屏不解析就不回答），**不是**收到乱码，所以别把"`count=0`"当成"屏的 TX 没接"。
  - **判据（最省事）**：发一条垃圾指令 `LCD zzz`，若 `LCDRD` 立刻读到 **`1A FF FF FF`**（或 `00 FF FF FF`）⇒ **波特率正确、双向都通**（淘晶驰对无法识别的指令会回错误码）。
  - 换波特率用 `LCDBAUD <n>`（运行时生效，不用重烧），或改 `lcd_init()` 的默认值；也可以在淘晶驰上位机里改屏侧并保存（`bauds`）。
- **帧格式：屏侧是 8N1（不开校验）** —— ⚠️ **别照抄 USART1 的 8E1**，两者帧格式不同是本项目特有的坑。
  （`board.c` 的 `lcd_init` 里 `USART3->CR1` 只设 `UE|TE|RE`，没有 `PCE`/`M`。）
- **`BRR` 要用 PCLK1 而不是 HCLK**：USART3 挂 APB1。当前 8MHz 时 PPRE1=/1 → PCLK1=8MHz；
  **M3 上 PLL 72MHz 后 PPRE1=/2 → PCLK1=36MHz**，那时若照抄 USART1 的算法波特率会**差一倍**。
  代码里已自动从 `RCC->CFGR` 推导（`pclk1_hz()`）。
- **回读**：`LCDRD` 返回屏发来的字节（触摸事件等）的十六进制 —— 排查"屏到底有没有在说话"时很有用。
- **接线**：屏 5V（预留 5V/1A）、GND 与主控**共地**；屏 `RX` ← 单片机 `PB10`(TX)，屏 `TX` → 单片机 `PB11`(RX)（**交叉**）。
- **⚠️⚠️ 中文编码：屏的字库是 `GBK`，PC 侧习惯用 `UTF-8` —— 两者不一致！**（2026-09-23 实测确认）
  - `LCD <内容>` 是**按字节原样转发**的（固件**不做**编码转换）→ **直接发 UTF-8 中文上去，屏上就是乱码**；ASCII 则完全正常（`t0.txt="ABC"` 实测 ✅）。
  - ✅ **ASCII 指令**（`page 0`、`t0.txt="12"`、`pic0.pic=5`）→ `LCD` 直接发。
  - ✅ **中文** → 必须走 **`LCDRAW <hex>`**，字节用 **GBK** 编码。例（实测屏上正常显示"红色方块"）：
    `t1.txt="红色方块"` → `LCDRAW 74312E7478743D22BAECC9ABB7BDBFE922FFFFFF`
  - 🛠 **现成工具：`09_固件\tools\lcd_hex.py`** —— `python lcd_hex.py --file <文本文件>` 直接吐出这串 hex。
    ⚠️ **带双引号的指令必须写进文件再用 `--file`** —— Windows PowerShell 5.1 会把参数里的 `"` 吃掉（实测踩过）。
  - ⚠️ **将来笔记本侧的分拣主程序也必须这么做**（Python 里 `text.encode("gbk")` → 发 `LCDRAW`），否则中文全是乱码；**固件侧不需要任何改动**。

---

## 8. 引脚映射表（提议，待评审）

避开：`PA11/PA12`（板载原生 USB）、`PA13/PA14`（SWD 调试，绝不占用）、`PB2`（BOOT1）、`PC13~PC15`（RTC/晶振）、`PC8/PC9`（板上 K3/K4 按键）。

| 功能 | 引脚 | 方向 | 备注 |
|---|---|---|---|
| 线协议 USART1_TX / RX | **PA9 / PA10** | 出 / 入 | 板载 CH340K，**固定不可改** |
| 串口屏 USART3_TX / RX | **PB10 / PB11** | 出 / 入 | |
| X 轴 STEP | **PA0** | 出 | TIM4 中断翻转 |
| X 轴 DIR | **PA1** | 出 | |
| X 轴 EN | **PA4** | 出 | 低有效（**待确认驱动器极性**） |
| Y 轴 STEP | **PA5** | 出 | |
| Y 轴 DIR | **PA6** | 出 | |
| Y 轴 EN | **PA7** | 出 | |
| Z 轴舵机 PWM | **PB0** | 出 | TIM3_CH3，50 Hz |
| 夹爪舵机 PWM | **PB1** | 出 | TIM3_CH4，50 Hz |
| 急停输入 | **PB7** | 入 | **EXTI，最高优先级**，内部上拉，低=急停 |
| 启动按钮 | **PB8** | 入 | 内部上拉 |
| 蜂鸣器 | **PB9** | 出 | |
| 微动：X 原点 | **PB12** | 入 | 内部上拉，低=触发 |
| 微动：Y 原点 | **PB13** | 入 | 同上 |
| 微动：夹爪触货 | **PB14** | 入 | 同上 |
| 微动：Z 低位 | **PB15** | 入 | 同上 |
| 入盒接收 1~6 | **PC0~PC5** | 入 | ⚠️ **这几个引脚不是 5V 容忍**，见 §11.4 |
| 入盒发射使能 1~6 | 待定（§11.3） | 出 | 做分时扫描才需要 |
| 备用 USART2 | PA2 / PA3 | — | 留给 ESP 调试期遥测（不参与闭环） |
| 调试 SWD | PA13 / PA14 | — | **保留** |

> **5V 容忍提醒**（F103 数据手册）：`PA0~PA7`、`PB0`、`PB1`、`PC0~PC5` 是模拟功能引脚，**不是 5V 容忍**；`PA8~PA15`、`PB2~PB15`、`PC6~PC12` 是 FT。
> 上表里这些非 FT 引脚**全是"从 MCU 往外驱动"或"接干接点"**，正常不会有 5V 倒灌；唯一风险是 §11.4 的红外模块供电电压。

---

## 9. 分阶段实现计划

| 里程碑 | 内容 | 判据（怎么算过了） | 依赖 |
|---|---|---|---|
| **M1 握手** ✅ **2026-09-22 实测通过** | USART1 收发 + 命令行解析 + 状态机 + `PING`/`VER`/`HELP`/`STATUS`/`GETPOS`/`BOX?`/`ESTOP`/`CLEAR`/`RESET` | 桥发 `PING` → 收 `OK pong`；发垃圾 → 收 `ERR 1 unknown`；**不接任何电机也能测** ✅ 全过 | 工具链（§11.1） |
| **M2 执行器** 🔶 **软件路径 2026-09-22 实测通过，待接舵机验证真脉冲** | 舵机 PWM（TIM3 CH3=PB0 Z 升降 / CH4=PB1 夹爪）+ 入盒 6 路 + `BOX_CHANGED` 事件 + `ZUP/ZDOWN/ZSET/ZPCT/GRIP/RELEASE/GSET/GPCT/SAFE` | 手动发 `ZUP`/`GRIP` 能看到动作 ⬜ **待硬件**；`BOX?` 与真实挡光一致 ⬜ **待硬件**；`ZSET/ZPCT` 与 `GETPOS` 回读一致 ✅ **已过** | 舵机已到货；**入盒红外仍未采买** |
| **M3 运动** | TIM4 步进引擎 + 回零 + 软限位 + `JOG`/`MOVE`/`HOME` | 回零可重复（连续 10 次零点漂移 ≤ 2 步）；越界被 `ERR 12` 挡住 | 驱动器接线（§11.2） |
| **M4 联调** | 与 AI 侧串起来跑单件分拣：拍照 → 判类 → `MOVE` → `ZDOWN` → `GRIP` → 抬起 → `MOVE` 到盒 → `RELEASE` → `BOX?` | 连续 12 件不掉、不误判、单盒 ≤4 件不超 | M1~M3 |

**M1 的价值**：它是"**AI 真的能驱动一块自己写的固件**"的最小闭环，而且**不需要任何执行器到货**就能做完 —— 所以它是第一优先级。

---

## 10. 烧录与工具链

### 10.1 现状（2026-09-21 实测本机）

| 工具 | 状态 |
|---|---|
| **Keil MDK 5.38** | ✅ **已安装**，但在非默认路径 `C:\111\keil\`（靠桌面快捷方式反查到的） |
| **armclang / armlink / armasm / fromelf** | ✅ `C:\111\keil\ARM\ARMCLANG\bin\` —— **命令行可用，已实测编译通过、无许可报错** |
| **CMSIS + STM32F1 标准外设库** | ✅ `Keil.STM32F1xx_DFP 2.4.1`（`stm32f10x.h`、`startup_stm32f10x_hd.s`、`StdPeriph_Driver` **23 个 .c**）+ `ARM::CMSIS 5.9.0`（`core_cm3.h`） |
| 独立 GNU 工具链 | ❌ `TOOLS.INI` 里的 `PATH1="…Arm GNU Toolchain…"` 是**失效残留**，文件不存在 |
| STM32CubeProgrammer / ST-LINK Utility / openocd | ❌ 无 |
| git | ✅ `C:\111\Git\cmd\git.exe` |
| make | ❌ 无 → 用 **Python 构建脚本**（本机 `D:\python\python.exe` 已有）代替 |

### 10.2 结论：**不需要安装任何东西** ✅（2026-09-21 实测）

构建链已经跑通，实测命令与结果：

```
armclang --target=arm-arm-none-eabi -mcpu=cortex-m3 -D STM32F10X_HD \
  -I <DFP>\Device\Include -I <CMSIS>\CMSIS\Core\Include -c xx.c -o xx.o
→ armclang exit = 0，产出 1008 字节 .o（无许可报错）
```

- 编译 `armclang.exe`（AC6）／链接 `armlink.exe`／转 bin `fromelf.exe --bin`，**都在 `C:\111\keil\ARM\ARMCLANG\bin\`**
- 需要三个 include 路径：① DFP `Device\Include` ② SPL `Device\StdPeriph_Driver\inc` ③ CMSIS `CMSIS\Core\Include`
- 无 `make` → **用 Python 脚本驱动构建**（本机已有 `D:\python\python.exe`，且我能直接读它的输出）
- **双轨产出**：① **命令行构建脚本**（**我能自己编译、自己看报错、自己迭代**）② **`.uvprojx` Keil 工程**（你能在 GUI 里打开、点"下载"烧录）
- ⚠️ 编译宏必须含 `STM32F10X_HD`（**高容量**，对应 RCT6 的 256KB flash + 48KB RAM；写成 MD 会少一堆外设定义）

### 10.3 烧录路径（两条都已具备条件）

1. **ST-Link V2 + SWD**（用户已有）：需要装 `STM32CubeProgrammer` 或 `openocd`。
2. **串口 ISP（无需任何额外硬件和软件）** —— **2026-09-21 已实测打通**：`BOOT0=1` + 复位 + `7F`/`00 FF`(GET)/`02 FD`(GetID) 全部正确应答。
   → **我可以把 AN3155 的 Erase + Write Memory + Go 写进桥**，让 AI 直接"编译完就自己烧、自己测"。这条路能让整个开发闭环**不依赖任何人工操作**，值得做（见 §11.5）。

---

## 11. 待确认事项（阻塞项）

| # | 事项 | 现状 / 建议 | 阻塞什么 |
|---|---|---|---|
| **11.1** | ~~工具链选型~~ **✅ 已解决（2026-09-21）** | **Keil MDK 5.38 已装在 `C:\111\keil\`**（非默认路径），`armclang` 命令行**实测编译通过、无许可报错**；CMSIS 5.9.0 + STM32F1xx_DFP 2.4.1（含 SPL 23 个 .c + `startup_stm32f10x_hd.s`）齐备 → **无需安装任何东西** | ~~阻塞 M1~~ → **不再阻塞，M1 已解锁** |
| **11.2** | **自备步进的驱动器接口** | 采购清单 C1 写的是"张大头 Emm42 闭环步进套装（已有）"，但清单第 9 行核对点仍开着：**EN 极性？STEP/DIR 能否 3.3V 直连？是否需要光耦灌电流接法？轴径 5/8mm？** | M3 无法接线 |
| **11.3** | **入盒检测是否做分时扫描** | 推荐做（彻底防串光）。需要**每路发射管可单独控制**：6 个 GPIO（引脚够）或 1 片 74HC138（省引脚，多一个件） | 定不下就没法锁 §8 引脚表 |
| **11.4** | **红外模块供电电压** | `PC0~PC5` **不是 5V 容忍**。建议**模块统一用 3.3V 供电**（LM393 支持 3.3~5V），则输出电平安全；若必须 5V 供电，则入盒输入改到 FT 引脚（`PC6/PC7/PC10/PC11/PC12` + 一个 FT 脚） | 影响硬件接线与引脚表 |
| **11.5** | **要不要做"串口 ISP 自动烧录"** | 建议做：桥里加 AN3155 的 Erase/Write/Go，AI 就能"编译→烧录→自测"全自动闭环 | 不影响 M1，影响开发效率 |
| **11.6** | **急停是否硬切电机电源** | **强烈建议**：急停常闭触点串进驱动器使能/电源。当前方案只有软件 EXTI | 影响接线与安全性 |

---

## 12. 变更记录

| 日期 | 变更 |
|---|---|
| 2026-09-21 | 首版。基于当日实测：CH340K 在 USART1@115200、需 `dtr/rts` 同时释放、bootloader V2.2、DEV_ID `0x0414`（真高容量 F103）、相机 1080P 在索引 1 |
| 2026-09-21 | §10 订正：**工具链已解决** —— Keil MDK 5.38 装在 `C:\111\keil\`，`armclang` 命令行编译实测通过（exit 0）。§11.1 阻塞项关闭 |

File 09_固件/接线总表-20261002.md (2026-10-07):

# 设备全接线总表（2026-10-02）

> 用途：把**全部**外设一次接上（X/Y 步进、Z 轴、夹爪、视觉、屏、红外、限位、按钮、蜂鸣器）。
> 引脚来源：`固件设计-协议与引脚.md` §8（提议表）+ 本次新增 **UART4 = 视觉(K210)**。
> **"固件"列 = 代码现在是否已经实现**：标 ❌ 的**先接线没问题**（引脚已预留），但**发命令不会有反应**，
> 要等对应模块写完（M3 步进引擎等）。

---

## A. STM32 侧信号接线

### A1. X / Y 步进（两个驱动器）

| # | 功能 | STM32 脚 | 接到驱动器 | 方向 | 固件 |
|---|---|---|---|---|---|
| 1 | X 轴 **PUL** | **PA0** | X 驱动 PUL+（或 PUL） | 出 | ❌ M3 未开工 |
| 2 | X 轴 **DIR** | **PA1** | X 驱动 DIR+ | 出 | ❌ |
| 3 | X 轴 **ENA** | **PA4** | X 驱动 ENA+ | 出 | ❌ |
| 4 | Y 轴 **PUL** | **PA5** | Y 驱动 PUL+ | 出 | ❌ |
| 5 | Y 轴 **DIR** | **PA6** | Y 驱动 DIR+ | 出 | ❌ |
| 6 | Y 轴 **ENA** | **PA7** | Y 驱动 ENA+ | 出 | ❌ |
| 7 | 驱动器 **PUL−/DIR−/ENA−** | — | **GND**（共阴接法，最常见） | — | — |

> ⚠️ **接口电平**：A4988 / DRV8825 / TMC 系列 **3.3V 可直连** ✓；
> **TB6600** 这类光耦输入驱动器通常要 **5V** ✗（3.3V 可能不触发）→ 要么用 5V 逻辑、要么加电平转换。
> ⚠️ **EN 极性**：多数驱动器**低有效**（拉低=使能）。接反了表现为"电机永远松着/永远锁着"，软件里可翻转。

### A2. 舵机（Z 轴升降 + 夹爪开合）

| # | 功能 | STM32 脚 | 接到舵机 | 固件 |
|---|---|---|---|---|
| 8 | Z 轴舵机信号 | **PB0** | 信号线（橙/黄/白） | ✅ 已实现（`ZSET/ZUP/ZDOWN/ZPCT`） |
| 9 | 夹爪舵机信号 | **PB1** | 信号线 | ✅ 已实现（`GSET/GRIP/RELEASE/GPCT`） |
| — | 两个舵机的 **V+** | — | **独立 5~6V 电源**（**绝不从板子取电**） | — |
| — | 两个舵机的 **GND** | — | **独立电源 −，且与 MCU 共地** | — |

> ⚠️ 舵机堵转电流可达 **2.5A/颗** → 电源要能出 **≥3A**，并在舵机电源两端并 **470~1000µF**。
> ⚠️ 共地！本项目已经因为漏共地出现过"MCU 不停复位"。

### A3. 视觉（CanMV / K210）—— **本次新增**

| # | 功能 | STM32 脚 | 接到 K210 | 固件 |
|---|---|---|---|---|
| 15 | K210 → STM32 | **PC11**（UART4_RX） | K210 **TX**（`UART2`，脚位看丝印） | ❌ 待写 |
| 16 | STM32 → K210 | **PC10**（UART4_TX） | K210 **RX**（`UART2`） | ❌ 待写 |
| — | 共地 | GND | GND | ⚠️ 必须 |

> 为什么用 **UART4**：USART1 被板载 CH340K（调试）占、USART2 给 ESP32-C6、USART3 给屏。
> `PC10/PC11` 还是 **FT（5V 容忍）** 脚，更保险。两侧都是 3.3V 电平 ✓ 直连。
> 备选：UART5（PC12 / PD2）。

### A4. 串口屏（淘晶驰）

| # | 功能 | STM32 脚 | 接到屏 | 固件 |
|---|---|---|---|---|
| 10 | 屏 **RX** | **PB10**（USART3_TX） | 屏 RX | ✅ |
| 11 | 屏 **TX** | **PB11**（USART3_RX） | 屏 TX | ✅ |
| — | 屏 **5V / GND** | — | 5V 轨 / GND | — |

> ⚠️ 屏是 **8N1 @9600**，USART1 是 **8E1** —— 两者帧格式不同，**别照抄**。
> 屏的指令必须以 **`FF FF FF`** 结尾；中文要 **GBK** 编码。

### A5. 无线（ESP32-C6）

| # | 功能 | STM32 脚 | 接到 C6 | 固件 |
|---|---|---|---|---|
| 13 | C6 → STM32 | **PA3**（USART2_RX） | C6 **GPIO4**（TX） | ✅ |
| 14 | STM32 → C6 | **PA2**（USART2_TX） | C6 **GPIO5**（RX） | ✅ |
| — | 共地 | GND | GND | ⚠️ 必须 |

> ⚠️ **波特率 115200 8N1**（不是 8E1）。**运行期应断电/断开**（规则红线：零外部通讯）。

### A6. 入盒检测（6 路红外对射）

| # | 功能 | STM32 脚 | 接到 | 固件 |
|---|---|---|---|---|
| 17 | 盒 1~6 接收 | **PC0 ~ PC5** | 6 个**接收端** OUT | ✅ 已实现（`BOX?`） |
| — | 接收端 VCC | — | ⚠️ **3.3V**（**不要 5V**） | — |
| — | 发射端（红外 LED） | — | 3.3V 或 5V **串限流电阻**（如 100~220Ω）；不做分时扫描就常亮 | — |

> ⚠️ `PC0~PC5` **不是 5V 容忍**（见 §11.4）→ 模块必须 3.3V 供电，否则可能打坏引脚。
> 逻辑：**挡光（有货）→ 低 → 对应 bit = 1**（内部上拉）。

### A7. 限位 / 按钮 / 蜂鸣器（**引脚已预留，固件全未实现**）

| # | 功能 | STM32 脚 | 接法 | 固件 |
|---|---|---|---|---|
| 19 | **急停** | **PB7** | 按钮一端 PB7、另一端 GND（内部上拉，低=急停） | ❌ |
| 20 | **启动按钮** | **PB8** | 同上 | ❌ |
| 21 | 蜂鸣器 | **PB9** | 有源蜂鸣器 + 三极管（或低电流直驱） | ❌ |
| 22 | X 原点微动 | **PB12** | 微动 COM→GND、**NO→PB12** | ❌ |
| 23 | Y 原点微动 | **PB13** | 同上 | ❌ |
| 24 | **夹爪触货微动** | **PB14** | 同上（★ 恒力夹取的"触到就停"判据） | ❌ |
| 25 | Z 低位微动 | **PB15** | 同上 | ❌ |

> ⚠️⚠️ **急停不能只给 MCU 一个信号** —— 必须**直接串在动力主回路里**（断电式急停），
> 否则 MCU 死机时急停就失效了。推荐：**急停开关用常闭触点串在总电源回路**，
> 同时**再引一路给 PB7** 让软件也知道。

### A8. 调试口

| 功能 | STM32 脚 | 说明 |
|---|---|---|
| 调试串口 | **PA9 / PA10** | 板载 CH340K（VID:PID `1A86:7522`）→ 电脑 `COM6`，**115200 8E1** |
| 烧录 | **PA13 / PA14** | SWD，**保留不许占用** |

---

## B. 电源怎么给

```
 6S 电池 22.2V (XT60)
   └─ 总开关 ─ 保险丝 ─ 【急停(常闭，串在动力回路)】
        ├─ XL4015 ──> 步进驱动器 Vmotor（12~24V，按你驱动器/电机额定）
        ├─ LM2596#1 ─> 6.0V / ≥3A ──> 两个舵机 V+（并 470~1000µF）
        ├─ LM2596#2 ─> 5V ──> STM32 板 5V 脚 ／ 串口屏 ／ K210 ／ ESP32
        └─ (STM32 板载 3.3V) ──> 红外接收端 ×6、微动开关上拉
```

| 负载 | 电压 | 电流（估） | 备注 |
|---|---|---|---|
| 步进驱动器 ×2 | **12~24V**（按型号） | 每轴 0.5~2A | 决定 Vmotor 用哪个降压 |
| 舵机 ×2 | **5~6.0V** | 峰值 **≥3A** | 堵转 2.5A/颗 |
| STM32 / 屏 / K210 / ESP32 | **5V** | ~0.6A | 屏约 200mA、K210 约 300mA |
| 红外接收 ×6 | **3.3V** | ~0.1A | ⚠️ 不能给 5V |

**上电顺序**（避免浪涌/乱动）：
1. 全部断电接线 → 2. 先只上 **5V 逻辑**（量电压、确认 MCU 正常起）→ 3. 上**舵机电源**（发 `GSET` 测动作）
→ 4. 最后上**步进 Vmotor**（听自锁声；此时还发不出脉冲，正常）

---

## C. 五条铁律

| # | 铁律 | 为什么 |
|---|---|---|
| 1 | **所有电源共地**（星形汇到一个点） | 漏共地 = MCU 不停复位（本项目管理过） |
| 2 | **舵机/步进绝不从 STM32 板取电** | 电流一冲就把 5V 拉垮 |
| 3 | **红外模块用 3.3V** | `PC0~PC5` 非 5V 容忍 |
| 4 | **步进信号电平看驱动器**（TB6600 要 5V） | 3.3V 可能不触发 |
| 5 | **运行期拔掉笔记本 USB** | 规则红线（零外部通讯）+ 避免地环路 |

---

## D. 现在接上之后，哪些能立刻动 / 哪些还不能

| 子系统 | 接上就能测 | 命令 |
|---|---|---|
| 舵机 ×2 | ✅ 立刻能动 | `GSET 1450`（夹爪）／`ZSET 1500`（Z 轴） |
| 串口屏 | ✅ 立刻能显示 | 透传指令（`FF FF FF` 结尾） |
| ESP32-C6 | ✅ 立刻能收发 | 无线链路 `PING → OK pong` |
| 入盒红外 6 路 | ✅ `BOX?` 能读 | `BOX?` / `BOX_CHANGED` |
| **X/Y 步进** | ❌ **不会动**（M3 未开工） | 要等我写步进引擎 |
| **限位/急停/按钮/蜂鸣器** | ❌ 不响应（固件未实现） | 同上 |
| **K210 视觉** | ❌ 未实现（UART4 驱动待写） | 同上 |

---

## E. 需要你确认三件事（定了我把 M3 写准）

| # | 要确认 | 为什么 |
|---|---|---|
| 1 | **步进驱动器型号**（A4988 / DRV8825 / TB6600 / 闭环？） | 决定 Vmotor 电压 + 能不能 3.3V 直驱 |
| 2 | **步进电机几线**（4 线 / 6 线） | 接线方式不同（6 线要决定接法） |
| 3 | **电池是不是 6S**（22.2V）？驱动器和降压模块的输入范围够吗？ | 决定降压链怎么搭 |

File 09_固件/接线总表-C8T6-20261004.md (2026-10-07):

# 接线总表 · **STM32F103C8T6** 版（2026-10-04 修订）

> 背景：原 **RCT6** 板因接线短路"很烫"报废 ✗ → 改用 **C8T6**（48 脚·中容量）。
> 固件已移植并**编译通过**：`-DSTM32F10X_MD`、64K flash / 20K RAM、栈顶 `0x20005000`
> ⇒ **ROM 22.5KB / 64KB，RAM 1.9KB / 20KB** ✓
>
> ⚠️⚠️ **上电前先做第 5 节的防短路检查** —— 上一块板就是这么烧的 ✗
> ⭐ 本版**不使用无线桥 ESP32-C6** ✗（用户 2026-10-04 决定）⇒ **USART2 给了串口屏** ✓

---

## 1. 一根线一张表（照这个接，按"从 → 到"读）

### ① 调试口（PC 看日志 / 发命令）

| 从 | 到 | 说明 |
|---|---|---|
| USB-TTL 的 **TXD** | C8T6 **PA10** | STM32 的 RX |
| USB-TTL 的 **RXD** | C8T6 **PA9** | STM32 的 TX |
| USB-TTL 的 **GND** | C8T6 **GND** | ⭐ 必须 |

**参数：115200 8E1** ⚠️（8N1 会是乱码）
⚠️ 经典蓝板**没有板载 USB 转串口** ✗ → 必须用 USB-TTL 转接板；若是"带 CH340 的 C8T6 板"则直接插 USB ✓

### ② 串口屏（淘晶驰）—— ⭐ 从 PB8 改到 PA2/PA3

| 从 | 到 | 说明 |
|---|---|---|
| C8T6 **PA2**（USART2_TX） | 屏的 **RX** | 固件→屏 |
| 屏的 **TX** | C8T6 **PA3**（USART2_RX） | 屏→固件（触摸事件，可不接） |
| 屏的 **GND** | C8T6 **GND** | ⭐ 必须 |
| 屏的 **5V** | 5V 逻辑电源 | 别从板子 5V 脚取大电流 ✓ |

**参数：8N1，出厂 9600** ⚠️ 屏侧波特率必须与固件一致（`LCDBAUD <n>` 可改固件侧 ✓）

### ③ 视觉板 CanMV/K210 —— ⭐ 从 PC10/PC11 改到 PB10/PB11

| 从 | 到 | 说明 |
|---|---|---|
| K210 的 **TXD** | C8T6 **PB11**（USART3_RX） | 计划/识别结果进来 |
| C8T6 **PB10**（USART3_TX） | K210 的 **RXD** | 回执出去 |
| K210 的 **GND** | C8T6 **GND** | ⭐ 必须 |

**参数：115200 8N1** ✓
⚠️ 这块 K210 板上标的 `TXD/RXD` **就是它的 UART2（控制台，与 USB 同一路）** ✓ 已实测
⚠️ 所以固件对这个口**只认 `@` 开头的行**、其余静默忽略 ✓（REPL 的输出不会误触发机构 ✓）

### ④ X 步进（X42 驱动器）

| 从 | 到 | 说明 |
|---|---|---|
| C8T6 **PA0** | X42 的 **Stp+**（PUL+） | 脉冲 |
| C8T6 **PA1** | X42 的 **Dir+** | 方向 |
| C8T6 **PA4** | X42 的 **En+** | 使能（低有效） |
| X42 的 **Stp− / Dir− / En−** | **GND** | 共阴接法 ✓ |
| X42 的 **V+** | **25.2V 电池正** | ⚠️ 直连，不经板子 |
| X42 的 **G / Com** | 电源 **GND**（星形共地点） | ⭐ |

### ⑤ Y 步进（第二个 X42）

| 从 | 到 |
|---|---|
| C8T6 **PA5** | Y42 的 **Stp+** |
| C8T6 **PA6** | Y42 的 **Dir+** |
| C8T6 **PA7** | Y42 的 **En+** |
| Y42 的 **Stp−/Dir−/En−** | **GND** |
| Y42 的 **V+ / G** | 25.2V 正 / 电源 GND |

### ⑥ 两个舵机

| 从 | 到 | 说明 |
|---|---|---|
| C8T6 **PB0** | **Z 轴**舵机信号线（橙/白） | TIM3_CH3，50Hz |
| C8T6 **PB1** | **夹爪**舵机信号线 | TIM3_CH4 |
| 两个舵机的 **V+（红）** | **5.5~6V 独立电源** | ⚠️ 不许接板子 5V ✗ |
| 两个舵机的 **GND（棕/黑）** | 电源 GND（同一共地点） | ⭐ |

### ⑦ 入盒红外 6 路 —— ⭐ 全部换脚（原 PC0~PC5 在 C8T6 上不存在 ✗）

| 盒号 | C8T6 引脚 | 接红外接收端的 **OUT** |
|---|---|---|
| 盒 1 | **PB12** | 1 号 |
| 盒 2 | **PB13** | 2 号 |
| 盒 3 | **PB14** | 3 号 |
| 盒 4 | **PB15** | 4 号 |
| 盒 5 | **PA8** | 5 号 |
| 盒 6 | **PA11** | 6 号（⚠️ 就是板上 USB 的 D−，**不用 USB 数据** ✓） |
| 接收端 **VCC** | **3.3V**（板载 3V3） | ⚠️ 不要 5V |
| 接收端 **GND** | GND | |
| 发射端 | 3.3V 经 **100~220Ω** 限流 | |

### ⑧ 暂时不接（固件还没实现 ✓，脚位先留着）

| 功能 | 引脚 |
|---|---|
| X / Y 原点限位 | **PA12 / PA15** |
| 夹爪触货 / Z 低位微动 | **PB3 / PB4** |
| 急停 / 启动按钮 / 蜂鸣器 | **PB5 / PB6 / PB7** |
| **SWD 烧录（必须留）** | **PA13 / PA14** → ST-Link |
| 空余 | **PB8、PB9、PC13** |

---

## 2. 引脚总览（一页版）

| 引脚 | 用途 | 引脚 | 用途 |
|---|---|---|---|
| PA0 | X 步进 PUL | PB0 | Z 舵机 |
| PA1 | X 步进 DIR | PB1 | 夹爪舵机 |
| PA2 | **串口屏 TX** | PB3 | （预留）夹爪触货 |
| PA3 | **串口屏 RX** | PB4 | （预留）Z 低位 |
| PA4 | X 步进 EN | PB5 | （预留）急停 |
| PA5 | Y 步进 PUL | PB6 | （预留）启动按钮 |
| PA6 | Y 步进 DIR | PB7 | （预留）蜂鸣器 |
| PA7 | Y 步进 EN | PB8 | **空余** |
| PA8 | **红外 盒5** | PB9 | **空余** |
| PA9 | 调试 TX | PB10 | **视觉 K210 TX** |
| PA10 | 调试 RX | PB11 | **视觉 K210 RX** |
| PA11 | **红外 盒6** | PB12 | **红外 盒1** |
| PA12 | （预留）X 原点 | PB13 | **红外 盒2** |
| PA13 | **SWD 必须留** | PB14 | **红外 盒3** |
| PA14 | **SWD 必须留** | PB15 | **红外 盒4** |
| PA15 | （预留）Y 原点 | PC13 | 空余 |

**不可用**：PC0~PC12 ✗、PC14/PC15（晶振）、PD0/PD1（晶振）、PB2（BOOT1）

---

## 3. 电源与共地（星形）

```
6S 电池 25.2V → 总开关 → 保险丝 →【急停（常闭，串在动力回路里）】
   ├──────────────────────> X42 / Y42 的 V+           ← 25.2V 直连 ✓
   ├─ 降压 5.5~6.0V / ≥3A ─> 两个舵机 V+（并 470~1000µF）
   └─ 降压 5V ────────────> 蓝板 5V 脚 ／ 串口屏 ／ K210
                              └─ 板载 3.3V ─> 6 路红外接收端
```

⭐ **所有"−"必须汇到同一个点**：电池 −（含两个驱动器的 G）＋ 舵机电源 − ＋ 蓝板 GND ＋ 屏 GND ＋ K210 GND ＋ USB-TTL GND

⚠️ **舵机/步进的电流绝不许走蓝板的地线或 5V 脚** ✗ —— 这是烧板第一原因

---

## 4. 上电顺序（严守）

| 步 | 上什么 | 检查什么 |
|---|---|---|
| 1 | **只插 USB-TTL**（不接动力 ✓） | 能看到 `LOG boot …`；发 `PING` → `OK pong` ✓ |
| 2 | **5V 逻辑**（屏 / K210） | 各板电源灯亮 ✓ |
| 3 | **舵机 6V** | `ZSET 1500`、`GSET 1450` 能动 ✓ |
| 4 | **最后上 25.2V** | 电机自锁（手拧不动）✓ |
| 5 | 全程 | ⚠️ 任何一块**发烫立刻断电** ✗ |

---

## 5. ⚠️⚠️ 上电前的防短路检查（上一块板就是这么没的）

**全部断电**，万用表逐个量：

| # | 量什么 | 期望 | 不通过 |
|---|---|---|---|
| 1 | 蓝板 **5V 脚 ↔ 25.2V 正** | **不通** | ⚠️ 通了 = 高压串进 5V，必烧 ✗✗ |
| 2 | 蓝板 **3V3 脚 ↔ 25.2V 正** | **不通** | 同上 |
| 3 | 蓝板 **5V ↔ GND** | **>100Ω** | 接近 0Ω = 板上有短路 ✗ |
| 4 | 蓝板 **3V3 ↔ GND** | **>100Ω** | 同上 |
| 5 | 舵机电源 + ↔ 蓝板 5V | 只经降压模块 | 直连 = 舵机电流全走板子 ✗ |

---

## 6. 接完的自检（fw 0.8.1）

| 命令 | 期望 | 验证了什么 |
|---|---|---|
| `PING` | `OK pong` | 板子活着 ✓ |
| `VER` | `OK fw=0.8.1 proto=1` | 版本 ✓ |
| `TIM3?` | `psc/arr/ccr3/ccr4…` | 舵机 PWM ✓ |
| `LCD zzz` | 屏回 `1A FF FF FF` | **串口屏（PA2/PA3）通** ✓ |
| `V4?` | `OK v4_rx=0 v4_tx=0 cr1=…` | **视觉口（USART3）通** ✓ |
| `BOX?` | `OK box=000000` | 6 路红外（逐路遮挡 → 对应位变 1 ✓） |
| `EN 1` → `ZERO all` → `STEP x 800` | 电机走 1/4 圈 | 步进通路 ✓ |
| `U2?` | `ERR 21 wireless bridge … disabled` | 无线桥已按预期停用 ✓ |

---

## 7. 与旧接线的差异清单（**必须改的 3 组**）

| 功能 | 旧（RCT6） | 新（C8T6） |
|---|---|---|
| 视觉 K210 | PC10 / PC11（UART4） | ⭐ **PB10 / PB11**（USART3） |
| 串口屏 | PB10 / PB11（USART3） | ⭐ **PA2 / PA3**（USART2，原无线桥的位置） |
| 入盒红外 1~6 | PC0 ~ PC5 | ⭐ **PB12 / PB13 / PB14 / PB15 / PA8 / PA11** |
| 无线桥 ESP32-C6 | PA2 / PA3 | ❌ **不接了**（用户决定） |
| 调试口 / 步进 / 舵机 / SWD | — | **完全不变** ✓ |

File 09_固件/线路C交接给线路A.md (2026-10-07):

# 线路 C → 线路 A 交接文档（STM32 固件 + 硬件联调）

> **交接时间**：2026-09-22
> **从**：线路 C（临时测试会话，用户指派"负责测试的分支"）
> **到**：线路 A（控制系统接入 + 摄像头，`hw_bridge` 的所有者）
> **原因**：线路 C 会话上下文过长、界面变卡，用户要求移交。
>
> **这份文档是自包含的** —— 不需要读线路 C 的对话记录就能接手。
> 项目级背景仍以 `..\Claude接续日志.md` 为准（线路 C 的完整结案记录在文末「🎯 / 🔧 / Z 轴行程标定结论」三节）。

---

## 0. 一句话现状

**M1 握手固件已验收通过；M2 舵机侧全通、Z 轴行程已标定、**入盒红外单路验证通过**（10 对已到货，剩 5 路未接）；**中断路径已打通（M3 前置解除）**；M3/M4 未开工。当前 fw = **0.2.2**。**

---

## 1. 最短上手路径（5 分钟）

```powershell
# ① 编译 + 经 ST-Link 烧录（不用拨 BOOT0）
powershell -File C:\Users\22431\Desktop\工创赛智能分拣项目\09_固件\flash_keil.ps1
```

```
# ② 串口验证（用 hw_bridge 的 MCP 工具）
serial_open(port='COM6', baud=115200, parity='E', dtr=false, rts=false)
serial_cmd('PING')      → OK pong
serial_cmd('VER')       → OK fw=0.2.0 proto=1
serial_cmd('STATUS')    → OK state=IDLE_UNHOMED homed=0 estop=0 box=000000 pos=0,0,0,0
serial_close()          # 用完记得关，串口是"一个进程一条连接"
```

**硬件事实**

| 项 | 值 |
|---|---|
| 主控 | **STM32F103RCT6** 最小系统板（DEV_ID `0x0414` = 高密度，真片） |
| 板载 USB-TTL | **CH340K**（SOP-8，VID:PID `1A86:7522`）接 **USART1 (PA9/PA10)** → 枚举为 **COM6** |
| 跳线 | **BOOT0 = 0**（串口 ISP 已不是必需路径；保持 0 让复位直接跑 App） |
| 烧录器 | ST-Link 接板上 `SWD接口`；**3.3V 不要接**（避免与板载供电打架） |
| Keil | `C:\111\keil\`，命令行 `C:\111\keil\UV4\UV4.exe` |
| 舵机 | **DS3225 270°** ×2（Z 轴 → PB0；夹爪 → PB1），**必须独立 5~6V 供电并与主控共地** |

---

## 2. 产物清单（都在 `09_固件\`）

| 路径 | 说明 | 改动注意 |
|---|---|---|
| `src\startup.c` | 向量表（段名 `RESET`，被 `m1.scf` 钉在 0x08000000）+ Reset_Handler + 手写 RW 拷贝/ZI 清零 | ⚠️ **向量表下标 = 16 + IRQn**；SysTick 在 index **15** |
| `src\board.c` / `board.h` | 时钟、USART1、SysTick、**TIM3 舵机 PWM**、**PC0~PC5 入盒扫描** | 开关都在文件头 |
| `src\main.c` | 命令解析、状态机、错误码、主循环（含入盒消抖与 `BOX_CHANGED` 事件） | `FW_VERSION` 在这里 |
| `src\boot_marker.h` | RAM 启动脚印地址表（诊断用，见 §5） | |
| `m1.scf` | 分散加载（flash 0x08000000 / RAM 0x20000000，栈顶 0x2000C000） | |
| `build.py` | 命令行构建（Keil 自带 `armclang/armlink/fromelf`，本机无 make）→ `build\m1.axf` + `m1.bin` | 产物后缀必须是 `.axf`（Keil 烧录只认它） |
| `keil\m1.uvprojx` + `m1.uvoptx` | Keil 工程（器件 STM32F103RC / ST-Link / `STM32F10x_512.FLM`） | ⚠️⚠️ **绝对不能带 UTF-8 BOM**（见 §4.2） |
| `flash_keil.ps1` | 一键"编译 → 烧录" | 用 `Start-Process -Wait` 调 UV4 |
| `tools\*.ps1` | 诊断/标定脚本（见 §3） | 含中文的 .ps1 **必须带 BOM** |
| `固件设计-协议与引脚.md` | **协议 v1.0 + 引脚表 + 里程碑 + 安全状态机**（权威） | 已更新到 fw 0.2.0 |

---

## 3. 诊断/标定工具（`09_固件\tools\`，全部已过语法检查）

| 脚本 | 用途 |
|---|---|
| `servo_jog.ps1` | **交互式点动**：回车=+步长、`-`=减、数字=跳转、`s N`=改步长、`q`=退出。标定行程端点用（自己掌握节奏，走到顶住就停手） |
| `servo_cal.ps1` | 按序列扫掠：`-Cmd ZSET -Values 1500,1100,1500` 或 `-Seq "50,10,90,50"` |
| `parity_sweep.ps1` | 一次扫「数据位 × 校验位」7 种组合 —— **当初定 8E1 真凶就是靠它** |
| `uart_listen.ps1` / `uart_raw.ps1` | 原始抓包（不经过桥的行切分逻辑，`uart_listen` 带时间戳） |
| `baud_sweep.ps1` | PC 侧扫波特率，反推板子真实主频 |

> **为什么这些脚本不走桥**：桥的 `serial_read` 按 `\n` 切行，二进制/乱码流会看不出结构。

---

## 4. 必读的 7 个坑（全是花时间换来的，别重走）

### 4.1 ⭐ 8E1 的真凶：`USART_CR1.M` 是"**含校验位在内**"的字长

| 配置 | 实际发出 |
|---|---|
| `M=0 + PCE=0` | 8 数据位 |
| `M=0 + PCE=1` | **7 数据位 + 1 校验位** ← 原来就是这个，还自以为在发 8E1 |
| `M=1 + PCE=1` | 8 数据位 + 1 校验位 ✅ |

PC 按 8E1 读 7+1，就把**校验位当成第 8 个数据位**。

**症状极具欺骗性**：帧同步完全正常（`\r\n` 原样、字符个数一个不差）、字符大体认得出来、只是**高位时不时多个 1** → 看着像干扰，其实是格式错。
**一句话判据**：把 PC 侧改成 **7E1** 一读就全对。（`parity_sweep.ps1` 就是干这个的。）
⚠️ 桥的 `serial_open` **只有 `parity`，没有 `data_bits`** —— 建议顺手补上，这类问题以后再遇到能一键定位。

### 4.2 Keil 工程文件**不能带 UTF-8 BOM**

带 BOM 时 `UV4 -f` **静默失败**：退出码 15、**连 `-o` 日志都不生成**，极难联想到 BOM。
对照：正确文件头 3 字节 `60 63 78`（`<?x`）；被 PowerShell 的 `Set-Content -Encoding utf8` 写过会变 `EF BB BF`。
（Windows PowerShell 5.1 的 `-Encoding utf8` 是**带 BOM** 的；要用 `[IO.File]::WriteAllText($p,$t,(New-Object Text.UTF8Encoding($false)))`。）

### 4.3 调 UV4 必须 `Start-Process -Wait`

`& UV4.exe ...` 对 GUI 子系统程序**立刻返回**（拿不到退出码，日志也来不及生成）。
Keil 烧完还会把内核留在停止态，`Application running ...` **不代表代码真在跑**。

### 4.4 打开串口会让板子复位 —— 所以"安全位"必须选**任何机构都安全**的位置

这块 CH340K 板**每次 `serial_open` 都会复位 MCU**。
我们把安全位写成"Z 抬到最高 = 2500µs"，结果**每开一次串口就把机构顶一次机械限位**，越顶越死。
→ **正解：安全位取中位 1500µs**（中位在任何机构上都安全），等行程方向拍板后再改。
> **教训：安全位要选"在任何机构上都安全"的位置，而不是"语义上正确"的位置。**

### 4.5 复位：只有 `dtr` 有效，`rts` 完全无效

- `serial_reset(mode='rts')` 对这块板**没有任何效果**（脉冲后不产生任何输出、也没有 banner）。
- `serial_reset(mode='dtr')` 才能复位。
- **DTR 的静态电平无所谓**：`serial_open(dtr:false)` 和 `dtr:true` 实测**都能正常收发**（旧文档里"DTR/RTS 会把 MCU 按在复位态"是误判）。

### 4.6 CH340 会掉驱动 → **僵句柄**

USB 拔插后 COM6 可能变成"注册表里还在、但打不开"（`Device COM6 is not currently available` / `OSError(22) Incorrect function`），
而且**桥的句柄会变成僵尸：读操作不报错，但永远读不到任何东西**。
→ **只能物理拔下等 5 秒再插回**。**判断"板子到底有没有在跑"之前，先确认串口打得开** —— 这一点曾让我们误判"固件不跑"好几轮。

### 4.7 写含中文的 `.ps1` 有三个坑

1. 文件**必须带 UTF-8 BOM**，否则 PS 5.1 按 ANSI 读 → `ParserError`。
2. **中文串里绝对不能出现 ASCII 直引号 `"`** → 会把字符串提前截断。
3. **别用 `[void](...)` 包住需要回显的调用** → 会把输出整行吞掉。
→ **交付脚本前先跑** `[System.Management.Automation.Language.Parser]::ParseFile()` **过语法，再喂输入做一次冒烟测试。**

---

## 5. 诊断手法（建议保留）

**RAM 启动脚印 + 寄存器快照**：外设寄存器不一定能读（bootloader 会 NACK 部分地址），但 **RAM 一直可读**。
所以固件把"跑到哪一步"和关键寄存器值写进 RAM，再"复位回 bootloader → 用 Read Memory 读出来"：

- 脚印：`BOOT_MARKER @ 0x2000B000`
- 寄存器快照：`0x2000B010`（`RCC_CFGR / RCC_CR / USART1->BRR / USART1->CR1`）
- 读法：`serial_cmd(hex="7F11EE2000B0009003FC", terminator="")`

另外固件里还有两个**默认关闭**的诊断开关，排查串口问题时很有用：
- `board.c: PROBE_BOOT=1` → 用 9 个不同 BRR 各发一句同样的话，**PC 上读得通的那一行 → f_cpu = 115200 × 那个 BRR**（实测只有 `brr=69` 干净）
- `main.c: HEARTBEAT=1` → 每秒重复输出一行已知字符串，**彻底摆脱对复位的依赖**

---

## 6. 未完成 / 下一步（按优先级）

| # | 事项 | 阻塞点 | 备注 |
|---|---|---|---|
| 1 | **入盒红外 6 路** | ❌ **还没采买** | 接 `PC0~PC5`，⚠️ **这几脚非 5V 容忍** → 模块必须 3.3V 供电，或把输入改到 FT 脚（`PC6/PC7/PC10/PC11/PC12`+1）。固件侧 `BOX?` 与 `BOX_CHANGED` 事件已就绪、含 1ms 二次采样消抖 |
| 2 | **夹爪行程标定** | 夹爪舵机未接 PB1 | 接上后 `servo_jog.ps1 -Cmd GSET`，找"完全张开 / 刚好夹住 40mm"两个值 |
| 3 | **Z 轴方向拍板** | 托盘/平台未装，看着连杆判不出来 | 装好后若反了发 `ZINV 1`（运行时生效，不用重烧） |
| 4 | **微动开关** | 未确认是否要装 | 现在 `EVT GRIP_DONE loaded=` **恒报 0**（"未确认"），没有假装知道夹住没夹住 |
| 5 | **M3 步进引擎** | ⚠️ 需用户告知自备驱动器接口（共阴/共阳、EN 极性、信号 3.3V 还是 5V） | TIM4 @20kHz 软件时基 + 回零 + 软限位 + `JOG/MOVE/HOME` |
| 6 | ~~**M3 前置隐患**：`systick_init()` 一开 TICKINT，`uart_puts` 就卡在等 TXE~~ **✅ 已查清并解决（2026-09-22，线路 A）** | ~~原因仍未查清~~ → **真凶是向量表下标错位** | **原来记的"SysTick 一开 TICKINT 就卡"是误判。** 真凶 `startup.c` 第 89-93 行它自己就记着：USART1 的向量被放到 IRQn 21、真正的 IRQn 37 位置是 0 → **"开中断 + RX 线上一个噪声起始位"就跳到地址 0 跑飞**；卡死恰好落在"开中断之后的第一次 `uart_puts`"，于是被错记成 SysTick。<br>**实验 1**（只开 SysTick）与**实验 2**（SysTick + `UART_RX_IRQ=1` 都开）**双双通过**：banner 完整、`PING → OK pong`。<br>**处置**：去掉 `__disable_irq()`、`UART_RX_IRQ` 改为 **1**（常态开中断），新增 **`MS?`** 命令自证 tick（实测 3.78 秒内 MCU 计时比 PC 计时只差 **3ms**，误差 0.08%）。**M3 的定时器中断路径已就绪。** |
| 7 | **M4 联调** | 依赖 M1~M3 | 拍照 → 判类 → `MOVE` → `ZDOWN` → `GRIP` → 抬起 → `MOVE` 到盒 → `RELEASE` → `BOX?` |

---

## 7. ⚠️ 线路 C 改动过线路 A 的文件（请知悉 / 自行复核）

| 文件 | 改了什么 | 生效方式 |
|---|---|---|
| `hw_bridge\server.py` | `_preview(data, limit=64)` → **`limit=4096`**（64 字节根本不够看一次自检的 9 行输出） | **必须 `Stop-Process` 杀掉那个 python 子进程**，mcp-client 约 1 秒后自动重连加载新代码 |
| `hw_bridge\protocol.md` | §4 订正 DTR 建议；新增 **8E1 / `CR1.M` 字长陷阱**、**复位（rts 无效、dtr 才有效）**、**复位后别 `DiscardInBuffer`** | 文档，直接生效 |

> 改桥的代码按线路 C 的规矩**应先问用户**；当时已在 `Claude接续日志.md` 里写了说明。**这两处请线路 A 复核是否保留。**

---

## 8. 当前板子状态（接手时应该就是这样）

- `BOOT0 = 0`
- flash 内 = fw **0.2.0**（`build/m1.bin`，约 10.7 KB）
- 串口 COM6 @ **115200 8E1**，**`serial_close()` 已关**（避免占住）
- Z 轴舵机停在 **中位 1500µs**（安全位）
- 夹爪通道 PB1 也在输出 1500µs，但**没接舵机**
- ST-Link 插在 `SWD接口` 上，3.3V 未接

**验收自测（贴着跑一遍就知道板子好不好）**

```
PING            → OK pong
VER             → OK fw=0.2.0 proto=1
STATUS          → OK state=IDLE_UNHOMED ... box=000000 pos=0,0,0,0
HELP            → OK commands=PING,VER,HELP,STATUS,GETPOS,BOX?,SAFE,ESTOP,CLEAR,RESET,ZUP,ZDOWN,ZSET,ZPCT,ZINV,GRIP,RELEASE,GSET,GPCT
TIM3?           → OK psc=7 arr=19999 ccr3=1500 ccr4=1500 cr1=129 ccer=4352 cnt=<变化> bcrl=... mapr=0 zinv=0
ZPCT 0          → GETPOS 显示 z=600
ZPCT 100        → GETPOS 显示 z=2400
ESTOP           → OK estop + EVT ESTOP reason=cmd；此后 ZUP → ERR 14
CLEAR           → OK cleared（并回安全位）
FOOBAR 1 2      → ERR 1 unknown FOOBAR
```

---

## 9. 交接后的边界

- **本会话（线路 C）就此停止改动 `09_固件\` 与 `hw_bridge\`。**
- 线路 A 接手后，如需与线路 B 协调，仍按 `Claude接续日志.md`「🔌 分工与交接」的规矩：**改对方占用的文件前先在日志里写一句**。
- 建议线路 A 接手后做的第一件事：**把 §4.1 的 `data_bits` 参数补进 `serial_open`** —— 这次那 40 分钟弯路的直接产物，成本极低、收益很高。

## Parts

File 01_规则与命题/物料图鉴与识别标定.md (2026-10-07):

# 工创赛物料图鉴与识别标定

> 依据：工作区 `工创赛物料/` 实拍照片 **20 张**（7 形状 × 3 色，缺 `蓝色-正方体`）
> 拼图总览：`工创赛物料/_总览_物料矩阵.jpg`（7 行 × 3 列，带中文标签）
> 自动统计原始数据：`05_工具与校核/_物料分析.txt`（脚本 `material_analysis.py`）
> 日期：2026-09-23 ｜ 用途：视觉识别标定 + 夹爪抓取参数 + 分拣映射

---

## 0 一句话结论

**颜色三维（绿/黄/蓝）实测可 100% 分开；但俯视轮廓有两组"撞车"——正方体与正四棱锥都是正方形、正三棱柱与正四面体都是三角形——必须补"高度"这一维，最省事的办法是让 Z 轴下探当高度探针。**

---

## 1 清单与完整度

| 形状 | 绿色 | 黄色 | 蓝色 | 俯视投影 |
|---|---|---|---|---|
| 正方体 | ✅ | ✅ | ❌ **缺** | 正方形 |
| 正三棱柱 | ✅ | ✅ | ✅ | 三角形（立放） |
| 正六棱柱 | ✅ | ✅ | ✅ | 六边形 |
| 圆柱 | ✅ | ✅ | ✅ | 圆形 |
| 正四棱锥 | ✅ | ✅ | ✅ | 正方形 + 4 条中心棱 |
| 正五棱锥 | ✅ | ✅ | ✅ | 五边形 |
| 正四面体 | ✅ | ✅ | ✅ | 三角形（躺放） |

- 实到 **20 张 / 21 格**，唯一缺口 `蓝色-正方体`（是漏拍，还是这批就没有蓝色正方体？见 §7）。
- 理论分拣组合 **7 × 3 = 21 类**；6 个储物盒 × 每盒 ≤4 件 = **24 个位**，容量够（初赛 ≥12 件）。

---

## 2 逐件几何与抓取分析

比例列为**照片目测**，只用于排序，精确值待卡尺实测（§7）。

| 形状 | 形体比例（目测） | 平行爪夹持 | 主要风险 | 对策 |
|---|---|---|---|---|
| 正方体 | 高 ≈ 边长 | ★★★★★ 两平行平面 | 无 | 标准参数，最大夹持力 |
| 正三棱柱 | 高 ≈ 边长（立放） | ★★★★ 两个侧面平行 | 立得高、重心高，快移易晃倒 | 中速、加减速限幅 |
| 正六棱柱 | 高 ≈ 0.4~0.5 × 对角 | ★★★★★ 对面组平行 | 无 | 标准参数 |
| 圆柱 | 高 ≈ 0.5~0.6 × 直径 | ★★ 线接触、会滚 | ①夹持接触面小、②托盘中滚动移位 | **必须用带齿 TPU 软垫**；托盘加浅挡边/凹槽；放置后不要抖动 |
| 正四棱锥 | 高 ≈ 0.4 × 底边（很扁） | ★★ 夹的是 4 个斜面 | 斜面产生**上抬分力**，易被"挤出" | 夹持点压到**离底面 3~6mm**、小夹持力、慢降慢升 |
| 正五棱锥 | 高 ≈ 0.5 × 对角（扁） | ★★ 夹的是 5 个斜面 | 同上 | 同上，另加"抓后停顿 100ms 自检" |
| 正四面体 | 躺放，高 ≈ 0.8 × 边长 | ★ 两个相邻斜面（楔形） | **最易滑脱/挤出**，且贴地薄 | 单独一组"轻抓低夹"参数：最小夹持力 + 最低夹持高度 + 最慢速度 |

**对夹爪 v2 的三条回推：**

1. **爪垫下沿必须能贴到离台面 2~3mm 的高度**——扁锥和四面体的有效夹持区只有底部一小条；爪体底面到爪垫下沿要留出这段余量（当前爪高 48mm、爪厚 3.5mm，需要确认"爪垫装好后最低能抓多低"）。
2. **TPU 1.5mm 爪垫要带齿**（已有 `grip_pad_gen.py` 锯齿垫），圆柱只靠平面接触是不够的。
3. **夹持分档**：至少"标准（方块/棱柱）/ 轻抓（锥/四面体）/ 圆柱"三组参数（夹持力、下降深度、速度），别用一套参数打天下。

---

## 3 颜色标定（实测 HSV，OpenCV 口径 H:0~179 / S,V:0~255）

在 20 张实拍照片上统计得到：

| 颜色 | 张数 | H 中位 | H 5%~95% | S 中位 | V 中位 | 建议识别窗 |
|---|---|---|---|---|---|---|
| 绿 | 7 | 83 | 77~85 | 248 | 179 | `H 71~90 & S≥190 & V≥110` |
| 蓝 | 6 | 101 | 100~104 | 150 | 221 | `H 93~109 & S≥90 & V≥150` |
| 黄 | 7 | 29 | 22~31 | 140 | 137 | `H 16~36 & S≥80 & V≥67` |

**三条注意：**

- **黄色最危险**：H 22~31 与木地板（H≈5~20 棕色）**只隔几个色相单位**，且黄件饱和度只有绿件的一半。→ ① 黄判定加 `S≥80` 门槛 + 面积滤波（≥300px）；② **托盘/货物摆放面用深灰哑光**，别用木色/黄色台面；③ 白光照明，不要暖光（暖光会把黄推向橙、把木地板推向黄）。
- **闪粉高光**：这批件是闪粉/丝绸料（顶面照片里能看到密集亮斑）。→ B3 乳白扩散罩的必要性再 +1，且相机必须**锁曝光**，否则高光点会让二值化面积忽大忽小。
- 三个色的 H 彼此间隔 ≥10，**白平衡漂移不影响判别**，只有黄/木这一对需要靠光照与背景控制。

---

## 4 俯视轮廓混淆矩阵（本轮最关键的一条）

固定俯视相机（B1）看到的是投影，**两组会撞车**：

| 俯视投影 | 可能来源 | 能否只看轮廓区分 | 区分办法 |
|---|---|---|---|
| 正方形 | 正方体、正四棱锥 | ❌ 不能 | 高度（正四棱锥只有正方体的 ~40%）；辅证：正四棱锥俯视有 4 条由中心发散的明暗棱线 |
| 三角形 | 正三棱柱、正四面体 | ❌ 不能 | 高度（四面体躺放 ≈ 0.8×边长，三棱柱立放 ≈ 1.0×边长）+ 顶面是否可见矩形侧面 |
| 圆形 | 圆柱 | ✅ 唯一 | — |
| 六边形 | 正六棱柱 | ✅ 唯一 | — |
| 五边形 | 正五棱锥 | ✅ 唯一 | — |

**推荐方案（零成本，已具备硬件）：把 Z 轴当"高度探针"。**

任务流程本来就是"走到货物上方 → 下降 → 夹取"，所以在**真正夹取之前**增加一次"轻触测高"：Z 轴慢速下探，检测到接触（步进堵转/失步电流拐点，或爪体上加一个微动开关）立刻停，记录下降行程 = 货物高度。三个好处：

1. 一次测量同时解决两组混淆（正方形组差 2.5 倍高度、三角形组差 ~20%）；
2. 顺便得到**抓取所需的精确下降深度**（比固定 Z 值稳，货物厚度有误差也不怕）；
3. 万一识别错，还有"下降到异常深度/没碰到"的兜底判据。

**备选**：① 低角度侧视相机（多一路相机 + 空间，性价比低）；② 只在俯视图上加"棱线/明暗"特征做辅证（可以叠加使用，但不作唯一依据）。

---

## 5 对视觉与补光方案的确认

| 结论 | 依据 |
|---|---|
| **2K + 3.6mm 低畸变镜头够用**（原结论维持） | 货物 ≤40mm、工作距离 ~215mm |
| **乳白扩散罩必须加** | 闪粉高光 + 圆柱顶面同心纹 |
| **锁曝光 + 固定白平衡**必须 | 黄件饱和度低，白平衡一漂就可能掉出 S≥80 |
| 只用白色/中性光，禁用暖光 | 保护"黄 vs 木色"这条最脆弱的边界 |
| 拍照在"夹爪完全离开盒口之后"再采样 | 沿用入盒检测同一条时序纪律 |

---

## 6 分拣映射（20 类 → 6 盒）

- 规则只要求**同形状同颜色进同一盒**，没要求不同类分盒；所以映射可以自由设计，唯一硬约束是 **每盒 ≤4 件**。
- 建议口述映射规则（写进说明书时用）：`盒号 = f(形状组, 颜色)`，形状分 3 组（方体/棱柱组、锥体组、圆与四面体组）× 颜色 3 色 = 9 格压到 6 盒，并对"每类件数"做在线计数，超 4 件自动换盒或报警。
- ⚠️ 待办：把这张映射表做成**固件里的表**（3 色 × 7 形状查表 → 盒号），别写死在代码分支里。

---

## 7 待确认（需要人回答）

| 编号 | 问题 | 为什么重要 |
|---|---|---|
| Q1 | **卡尺实测**每个形状：外接圆/边长、总高（mm） | 决定爪垫最低夹持高度、Z 下降深度、托盘挡边高度 |
| Q2 | `蓝色-正方体` 是**漏拍**，还是这批**没有**蓝色正方体？ | 21 类还是 20 类，影响映射表与自检总量 |
| Q3 | 这批是**自打印测试件**，还是赛方发的？材质是 PLA 闪粉？ | 摩擦系数（μ）与重量 → 决定夹持力档位 |
| Q4 | 初赛现场是**只有 3 色**，还是色数更多？ | 规则写"种类不少于 6 种"，颜色维度可能被临时扩展 |
| Q5 | 各件**重量**（克） | 校核夹持力 3× 重力安全余量 |

---

## 附：本轮新增的工具

| 文件 | 作用 |
|---|---|
| `05_工具与校核/material_analysis.py` | 批量分割物料照片 → 输出 HSV 统计、轮廓比例、完整度表（写 `_物料分析.txt`） |
| `05_工具与校核/material_sheet.py` | 把散照片拼成带中文标签的"7 形状 × 3 色"矩阵总览图 |
| `工创赛物料/_总览_物料矩阵.jpg` | 上述拼图产物（1112 × 2514），可直接发队友对照 |

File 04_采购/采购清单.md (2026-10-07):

# 工创赛智能分拣机器人 · 采购清单

> **2026-09-17 晚更新（第二次）**：按用户口径**剔除已有/自备物品** —— ST-Link、USB 转 TTL（CH340）、ESP 模块、**步进电机（X/Y 轴，已自备）**、**电源系统除"锂电池 + 平衡充电器"外全部**、**4040 铝型材**、**3D 打印耗材**、**全部工具类**；**OpenMV 确认不需要**。
> 同时并入两项设计变更：**① 夹爪 v2（2026-09-17 复核：开口 64、舵机须 270° 版、每爪 2 根导杆，见 `03_设计与尺寸\夹爪设计参数表.md` §0）② 深向改 MGN 线轨**（350mm 导轨 + 45 滑块只有 305 行程，且前探要允许滑块悬出 ~14mm → **光轴+LM8UU 会掉滚珠，不能用**；宽向行程富余，仍可用光轴）。
> 依据：II-2 官方规则 PDF + 《II-2规则要点与搬运赛道对照.md》 + 已拍板的方案 B（龙门 XYZ + 舵机夹爪）。
> **预算：约 1050~1600 元**（原 1600~2200；去掉自备件、加上 MGN 线轨与夹爪增补）。
>
> ⚠️ **下单前 6 个核对点**：
> 1. **自备步进**：核对**轴径（5mm/8mm）**、**是否带驱动器**、**脉冲接口能 3.3V 直连**——同步轮/联轴器按它下单（C7）
> 2. **USB 摄像头问客服"能否锁定手动曝光"**，不能锁的一律不买
> 3. 电池动力头是 **XT60** 不是 T 插；**必配 6S 平衡充电器**
> 4. 串口屏买**淘晶驰 USART HMI 类**（自带字库/图片、串口指令控制），别买裸 TFT
> 5. **舵机必须买 DS3225 的 270° 版**（夹爪 v2 全行程 56mm 需 152.8° 转角；180° 版要把齿轮改成 M1.5-z16、本体高变 30）
>    ⚠️ **2026-10-02 补充（线路 A 实测）**：目前实装的是 **MG996R（~180°）**，**不是** 270° 版 ——
>    实测全量程爪口行程只有 **≈46mm**（设计 56mm）、开口端 **60mm**。
>    **买 C2 时务必确认是 270° 版**；是否立刻补买待拍板（见 `03_设计与尺寸\夹爪设计参数表.md` 顶部 2026-10-02 注）。
> 6. 同步带长度、光轴/MGN 长度、板材尺寸**等三维建模定稿后按图买**（第三批），别先拍脑袋

---

## ✅ 已有 / 自备（**不采购**，但要核对规格）

| 类别 | 已有物品 | 还要核对什么 |
|---|---|---|
| 主控外围 | **ST-Link V2**、**CH340 USB 转 TTL**、**ESP 模块/芯片** | ESP 若是裸芯片（非模块）需转接板；CH340 建议有 1 个备用 |
| 驱动 | **步进电机（X/Y 轴，自备）** | ⚠️ **轴径 5/8mm？带不带驱动器？脉冲版能否 3.3V 直连 STM32？**（这决定 C6 同步轮/联轴器） |
| 结构 | **4040 铝型材（够用）** | ⚠️ 按《框架与布局尺寸.md》下料共 **≈4.2m**（4×260 立柱 + 8×270 框梁 + 2×350 导轨梁 + 1×270 Y 梁）；**角件/T 型螺母/中心连接件够不够** |
| 耗材 | **3D 打印耗材** | ⚠️ 用量不小：6 个储物盒 + 托盘 + 夹爪整套 + 各支架；确认 PLA 库存与打印机可用 |
| 电源 | 低压报警蜂鸣器、总开关、保险丝座、急停开关、一键启动按钮、XL4015、LM2596/Mini360、电解电容、XT60 插头、洞洞板 | 降压模块**输出档位能否调到舵机要的电压**；电容耐压 ≥35V |
| 工具 | 电烙铁/焊锡/吸锡器、剥线钳/斜口钳、内六角套装、热熔胶枪、万用表、电工胶带/双面胶 | 焊 XT60/开关/保险丝要有大功率烙铁 |

> 以上**均不进采购单**；若核对时发现缺项，按对应规格补买即可。

## A. 主控

| # | 物品 | 数量 | 参考价 | 备注 |
|---|---|---|---|---|
| A1 | STM32F103RCT6 最小系统板 | 1（建议备 1） | ~35 元/块 | 2 路步进脉冲+方向、2 路舵机 PWM、串口屏/笔记本串口、6 路入盒检测、限位开关；**板子本身不在"已有"里，要买** |

## B. 视觉

| # | 物品 | 数量 | 参考价 | 备注 |
|---|---|---|---|---|
| B1 | USB 摄像头（1080P 广角免驱、**可锁手动曝光**） | 1 | 50~100 元 | **AI 识别主力**：固定在托盘正上方俯视，笔记本跑 OpenCV 识别颜色/形状/文字/二维码。⚠️ 下单前问客服"能否锁定手动曝光" |
| B2 | ~~OpenMV H7~~ | **不需要** | — | **2026-09-17 确认：不需要**（识别任务笔记本全包；规则也不要求车载视觉） |
| B3 | 环形 LED 补光灯（白光，带漫射罩） | 1 | ~20 元 | 俯视识别补光，压环境光干扰；规则允许装置自带补光 |

## C. 运动与执行（龙门 XYZ + 夹爪）

| # | 物品 | 数量 | 参考价 | 备注 |
|---|---|---|---|---|
| C1 | ~~张大头 Emm42 闭环步进套装~~ | **已有/自备** | — | X/Y 轴用自备步进（见上表"已有"）。⚠️ **闭环对定位更稳**，自备若是普通开环步进，把速度降下来并留足惯量余量 |
| C2 | **DS3225 级 PWM 舵机（25kg 金属齿，270° 版）** | 4 个 | 25~35 元/个 | Z 轴升降×1 + 夹爪开合×1 + 备件×2。⚠️ **必须 270° 版**（夹爪 v2 需 152.8°）；舵机无反馈 → 靠微动开关到位检测 |
| C3 | 舵机金属摇臂/法兰盘 | 4 | ~5 元/个 | 买舵机常附赠塑料臂；夹爪齿轮要拧在舵机盘上，建议上金属臂（4×M3 顶丝压紧无间隙） |
| C4 | 同步带 GT2/GT3 + 同步轮 + 张紧轮套装 | 1 套 | 40~60 元 | X/Y 传动；开源资料教训：**同步带精度高于齿轮齿条**。长度第三批按图定 |
| C5 | **深向（Y）MGN12 线轨 + 滑块** | 导轨 350mm×2 + 滑块 4 | 130~200 元 | ⚠️ **深向必须用线轨**：350 导轨 + 45 滑块只有 305 行程，前探还需滑块悬出 ~14mm —— **光轴+LM8UU 悬出会掉滚珠，绝对不行**。滑块可选短款 MGN12C（35）多换 10mm 行程 |
| C6 | 宽向（X）Ø8 光轴 + LM8UU + 支撑座 | 1 套 | 50~80 元 | 宽向行程富余（225 需 176），可用光轴；长度第三批按图定 |
| C7 | 同步轮/联轴器与步进轴的配套件 | 2 套 | ~15 元/套 | ⚠️ 按自备步进的**轴径（5mm/8mm）**下单 |
| C8 | 微动开关（限位/触货） | **8 个** | ~1 元/个 | X/Y 原点各 1 + 夹爪触货 1 + Z 低位 1 + 备 4（v2 由 5 个加量到 8 个） |
| C9 | **夹爪增补件**（见《夹爪设计参数表.md》§5） | 1 套 | **25~40 元** | ① MF106ZZ 带法兰微型轴承 6×10×3 ×（4+2 备）② **Ø6 导杆 ≈44mm ×4 根**（v2 每爪 2 根）③ 压簧（预压 3~5N，外径 ≤6、长 10~15，**买几种刚度试**）④ **爪垫**（TPU 打印或 3M 泡棉 2mm）⑤ **M1.5 成品齿条 100mm**（自打印齿隙大时兜底）。⚠️ 齿轮/齿条一律**自打印**（100% 填充 + 0.15mm 层高），不买成品套件 |

## D. 传感器（入盒检测）

| # | 物品 | 数量 | 参考价 | 备注 |
|---|---|---|---|---|
| D1 | **红外对射对管（发射+接收分体，带 LM393 比较器模块，3.3~5V 数字输出）** | 6 对（+2 对备） | 3~5 元/对 → **20~45 元** | **6 个储物盒各 1 路**：规则要求"货物必须全部进入储物盒才计分"，必须有硬件确认。**选对射不选漫反射**：对射不看货物颜色/反射率（黑色泡沫、带污渍的货都能测），跨盒 82mm 光路足够 |
| D2 | （备选/兜底）低操作力杠杆微动开关 | 6（+2 备） | 1~2 元/个 | 货落下压住杠杆即计数，**纯机械、颜色无关、更便宜**。⚠️ 货只有 20~50g，普通微动操作力 50~150gf **可能压不动** → **必须先用真货实测**；选型挑 ≤30gf 的 |
| D3 | （加强，可选）每盒 1 路对射 + **俯视相机复核** | — | 0 元（用已有相机） | 双确认：相机看"该格是否有货"作为软件冗余，防单点失效（规则里"未全入盒不计数"，宁可多一层） |

> ⚠️ **为什么不能用 E18-D80NK（原清单那款）**：① 它是 **M18 圆柱、长约 60mm**，而**爪子下潜外廓 71mm 对盒内腔 82mm，单侧只剩 5.5mm** → **塞不进盒内**；② 漫反射最短检测距离 ~3cm，而盒内净空只有 **45mm（货 40mm）** → 贴脸检测不可靠；③ 漫反射对**黑色/低反射货**容易失灵。
>
> ⚠️ **安装与采样的两条硬要求（要写进建模与状态机）**：
> 1. **传感器腔做在盒壁"外侧凸台"上**（外壁局部加厚 6~8mm 挖腔，对射管贴盒内壁底部离底 5~10mm）——**内腔 82 一点不能减**（4 件 40mm 货的容量红线）。
> 2. **采样时机必须在爪子抬起、离开该盒口之后**再读这一路——爪子本身会遮断光路，边放边读会误判。状态机里把"入盒确认"排在"Z 轴抬升 + 横移离开"之后。

## E. 显示

| # | 物品 | 数量 | 参考价 | 备注 |
|---|---|---|---|---|
| E1 | 淘晶驰串口屏 3.5 寸（480×320，USART HMI） | 1 | 60~90 元 | 规则要求**高亮彩屏、能播图片**：逐件显示序号/货物名称/图片/成功总数。货物图片预存屏内，串口发指令切换。⚠️ 别买成裸 TFT |

## F. 电源系统（**只剩电池与充电器要买**）

| # | 物品 | 数量 | 参考价 | 备注 |
|---|---|---|---|---|
| F1 | 6S（24V）2200~3000mAh 25C 航模锂电 | 1 包 | 180~280 元 | 格氏 Gens Ace / Tattu **品牌官方旗舰店**。⚠️ 动力头确认 **XT60** 不是 T 插；规则禁止赛中换电池，单包即可 |
| F2 | 6S 平衡充电器（B6 类） | 1 | 100~150 元 | ⚠️ **必买**，没它 6S 电池无法充电；确认支持 6S |
| F3 | ~~低压报警/总开关/保险丝/急停/启动按钮/降压模块/电容/XT60/洞洞板~~ | **已有或自备** | — | 见上方"已有"表；核对降压模块能否调到舵机所需电压 |

## G. 线材与连接

| # | 物品 | 数量 | 参考价 | 备注 |
|---|---|---|---|---|
| G1 | TRVV 柔性拖链电缆一卷（0.3~0.5mm² 多芯） | 1 卷 | 30~50 元 | 龙门 X/Y 运动走线反复弯折，**必须用拖链电缆**。⚠️ 国特队 FC 灰排线磨破烧 Jetson 的教训 |
| G2 | 硅胶导线 18~22AWG | 红黑各若干米 | ~20 元 | 动力回路，耐大电流耐高温 |
| G3 | 杜邦线 + 排针排母套装 | 1 套 | ~15 元 | 信号连接、调试飞线（若实验室有可省） |
| G4 | 热缩管套装 | 1 盒 | ~10 元 | 焊点绝缘 |
| G5 | 扎带 + 缠绕管/蛇皮管 + 小型拖链 | 各 1 | ~20 元 | 龙门架理线，防磨防刮 |

## H. 结构材料与紧固件

| # | 物品 | 数量 | 参考价 | 备注 |
|---|---|---|---|---|
| H1 | ~~铝型材 2020 等~~ | **已有 4040（量够）** | — | 按图下料 ≈4.2m；⚠️ 另需**角件/端面攻丝 M8/中心连接件/T 型螺母**，缺了要补 |
| H2 | 玻纤板/亚克力板（底板 + 挡板） | 按需 | 40~60 元 | 底板 270×350（或 350×350 四角开缺口，详见《框架与布局尺寸.md》§6）；打印件前先切木板验证 |
| H3 | M3/M4 螺丝螺母垫圈套装 | 1~2 盒 | ~20 元/盒 | 模块化要求"拆任一部件 ≤5 颗螺丝"，备足标准件 |
| H4 | M3 铜柱（双通/单通混合） | 若干 | ~10 元 | 主控板、降压模块、传感器架空固定 |
| H5 | ~~3D 打印耗材~~ | **已有/自备** | — | ⚠️ 确认库存：6 盒 + 托盘 + 夹爪整套 + 支架，用量不小；PLA 优先（齿轮/齿条 100% 填充、0.15mm 层高） |
| H6 | 木板/KT 板（试切验证用） | 若干 | ~20 元 | 打正式件前先切木板验证装配 |

## I. 工具与耗材

**全部已有/自备，不采购。** 上电前自检清单：电烙铁（要大功率，焊 XT60）+ 焊锡/吸锡器 · 剥线钳/斜口钳 · 内六角套装 · 热熔胶枪 · **万用表（量各路电压再上电）** · 电工胶带/双面胶。

---

## 预算估算

| 类别 | 小计 |
|---|---|
| A 主控 | 35~70 元 |
| B 视觉 | 70~120 元 |
| C 运动与执行（舵机 + 线轨 + 同步带 + 光轴 + 夹爪增补） | 390~570 元 |
| D 传感器 | 30~45 元（对射 6 对 20~45；微动备选更便宜） |
| E 显示 | 60~90 元 |
| F 电源（只剩电池 + 充电器） | 280~430 元 |
| G 线材与连接 | 95~130 元 |
| H 结构材料（板材/标准件） | 90~130 元 |
| **合计（工具类不计，已自备）** | **约 1050~1600 元** |

> 相比上一版（1600~2200）省下的是：步进电机（250~330）、铝型材（60~100）、3D 耗材（100~140）、电源杂项（~60）、工具类；新增的是 **深向 MGN12 线轨（130~200）** 与 **夹爪增补件（25~40）**。
> 若自备的步进不带驱动器/或需要新驱动器，再追加 2×30~60 元。

## 下单顺序建议

1. **第一批（立即）**：**A1 主控、B1+B3 视觉与补光、C2 舵机（270° 版）、F1+F2 电池与充电器** —— 到货周期长，且"让机构动起来/看得见"阶段全要用
2. **第二批（建模前）**：C3~C9、D1、E1、G 全部 —— 便宜件一次凑齐省运费
3. **第三批（建模定稿后按图买）**：C4 同步带长度、C5 MGN 导轨长度、C6 光轴长度、H2 板材尺寸 —— **长度/规格全部按三维图买**

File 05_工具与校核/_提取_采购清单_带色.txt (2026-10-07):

工创赛智能分拣机器人 · 采购清单
{C=333333}2026-09-17 晚更新（第二次）{/}{C=333333}：按用户口径{/}{C=333333}剔除已有/自备物品{/}{C=333333} —— ST-Link、USB 转 TTL（CH340）、ESP 模块、{/}{C=333333}步进电机（X/Y 轴，已自备）{/}{C=333333}、{/}{C=333333}电源系统除"锂电池 + 平衡充电器"外全部{/}{C=333333}、{/}{C=333333}4040 铝型材{/}{C=333333}、{/}{C=333333}3D 打印耗材{/}{C=333333}、{/}{C=333333}全部工具类{/}{C=333333}；{/}{C=333333}OpenMV 确认不需要{/}{C=333333}。{/}{C=333333}同时并入两项设计变更：{/}{C=333333}① 夹爪 v2（2026-09-17 复核：开口 64、舵机须 270° 版、每爪 2 根导杆，见 {/}{C=333333}03_{/}{C=333333}设计与尺寸{/}{C=333333}\{/}{C=333333}夹爪设计参数表{/}{C=333333}.md{/}{C=333333} §0）② 深向改 MGN 线轨{/}{C=333333}（350mm 导轨 + 45 滑块只有 305 行程，且前探要允许滑块悬出 ~14mm → {/}{C=333333}光轴+LM8UU 会掉滚珠，不能用{/}{C=333333}；宽向行程富余，仍可用光轴）。{/}{C=333333}依据：II-2 官方规则 PDF + 《II-2规则要点与搬运赛道对照.md》 + 已拍板的方案 B（龙门 XYZ + 舵机夹爪）。{/}{C=333333}预算：约 1050~1600 元{/}{C=333333}（原 1600~2200；去掉自备件、加上 MGN 线轨与夹爪增补）。{/}{C=333333}⚠️{/}{C=333333} {/}{C=333333}下单前 6 个核对点{/}{C=333333}：{/}{C=333333}1. {/}{C=333333}自备步进{/}{C=333333}：核对{/}{C=333333}轴径（5mm/8mm）{/}{C=333333}、{/}{C=333333}是否带驱动器{/}{C=333333}、{/}{C=333333}脉冲接口能 3.3V 直连{/}{C=333333}——同步轮/联轴器按它下单（C7）{/}{C=333333}2. {/}{C=333333}USB 摄像头问客服"能否锁定手动曝光"{/}{C=333333}，不能锁的一律不买{/}{C=333333}3. 电池动力头是 {/}{C=333333}XT60{/}{C=333333} 不是 T 插；{/}{C=333333}必配 6S 平衡充电器{/}{C=333333}4. 串口屏买{/}{C=333333}淘晶驰 USART HMI 类{/}{C=333333}（自带字库/图片、串口指令控制），别买裸 TFT{/}{C=333333}5. {/}{C=333333}舵机必须买 DS3225 的 270° 版{/}{C=333333}（夹爪 v2 全行程 56mm 需 152.8° 转角；180° 版要把齿轮改成 M1.5-z16、本体高变 30）{/}{C=333333}6. 同步带长度、光轴/MGN 长度、板材尺寸{/}{C=333333}等三维建模定稿后按图买{/}{C=333333}（第三批），别先拍脑袋{/}
✅ 已有 / 自备（不采购，但要核对规格）
[TABLE]
  | 类别 | 已有物品 | 还要核对什么
  | {C=4EA72E}主控外围{/} | {C=4EA72E}ST-Link V2{/}{C=4EA72E}、{/}{C=4EA72E}CH340 USB 转 TTL{/}{C=4EA72E}、{/}{C=4EA72E}ESP 模块/芯片{/} | {C=4EA72E}ESP 若是裸芯片（非模块）需转接板；CH340 建议有 1 个备用{/}
  | {C=4EA72E}驱动{/} | {C=4EA72E}步进电机（X/Y 轴，自备）{/} | {C=4EA72E}⚠️{/}{C=4EA72E} {/}{C=4EA72E}轴径 5/8mm？带不带驱动器？脉冲版能否 3.3V 直连 STM32？{/}{C=4EA72E}（这决定 C6 同步轮/联轴器）{/}
  | {C=4EA72E}结构{/} | {C=4EA72E}4040 铝型材（够用）{/} | {C=4EA72E}⚠️{/}{C=4EA72E} 按《框架与布局尺寸.md》下料共 {/}{C=4EA72E}≈4.2m{/}{C=4EA72E}（4×260 立柱 + 8×270 框梁 + 2×350 导轨梁 + 1×270 Y 梁）；{/}{C=4EA72E}角件/T 型螺母/中心连接件够不够{/}
  | 耗材 | 3D 打印耗材 | ⚠️ 用量不小：6 个储物盒 + 托盘 + 夹爪整套 + 各支架；确认 PLA 库存与打印机可用
  | 电源 | 低压报警蜂鸣器、总开关、保险丝座、急停开关、一键启动按钮、XL4015、LM2596/Mini360、电解电容、XT60 插头、洞洞板 | 降压模块输出档位能否调到舵机要的电压；电容耐压 ≥35V
  | 工具 | 电烙铁/焊锡/吸锡器、剥线钳/斜口钳、内六角套装、热熔胶枪、万用表、电工胶带/双面胶 | 焊 XT60/开关/保险丝要有大功率烙铁
[/TABLE]
{C=333333}以上{/}{C=333333}均不进采购单{/}{C=333333}；若核对时发现缺项，按对应规格补买即可。{/}
A. 主控
[TABLE]
  | # | 物品 | 数量 | 参考价 | 备注
  | {C=4EA72E}A1{/} | {C=4EA72E}STM32F103RCT6 最小系统板{/} | {C=4EA72E}1（建议备 1）{/} | {C=4EA72E}~35 元/块{/} | {C=4EA72E}2 路步进脉冲+方向、2 路舵机 PWM、串口屏/笔记本串口、6 路入盒检测、限位开关；{/}{C=4EA72E}板子本身不在"已有"里，要买{/}
[/TABLE]
B. 视觉
[TABLE]
  | # | 物品 | 数量 | 参考价 | 备注
  | {C=4EA72E}B1{/} | {C=4EA72E}USB 摄像头（1080P 广角免驱、{/}{C=4EA72E}可锁手动曝光{/}{C=4EA72E}）{/} | {C=4EA72E}1{/} | {C=4EA72E}50~100 元{/} | {C=4EA72E}AI 识别主力{/}{C=4EA72E}：固定在托盘正上方俯视，笔记本跑 OpenCV 识别颜色/形状/文字/二维码。{/}{C=4EA72E}⚠️{/}{C=4EA72E} 下单前问客服"能否锁定手动曝光"{/}
  | {C=4EA72E}B2{/} | {C=4EA72E}~~OpenMV H7~~{/} | {C=4EA72E}不需要{/} | {C=4EA72E}—{/} | {C=4EA72E}2026-09-17 确认：不需要{/}{C=4EA72E}（识别任务笔记本全包；规则也不要求车载视觉）{/}
  | 〔#0起〕{C=4EA72E}B3{/} | {C=4EA72E}环形 LED 补光灯（白光，带漫射罩）{/} | {C=4EA72E}1{/} | {C=4EA72E}~20 元{/} | {C=4EA72E}俯视识别补光，压环境光干扰；规则允许装置自带补光{/}〔#0止〕【批注#0】
[/TABLE]
C. 运动与执行（龙门 XYZ + 夹爪）
[TABLE]
  | # | 物品 | 数量 | 参考价 | 备注
  | {C=4EA72E}C1{/} | {C=4EA72E}~~张大头 Emm42 闭环步进套装~~{/} | {C=4EA72E}已有/自备{/} | {C=4EA72E}—{/} | {C=4EA72E}X/Y 轴用自备步进（见上表"已有"）。{/}{C=4EA72E}⚠️{/}{C=4EA72E} {/}{C=4EA72E}闭环对定位更稳{/}{C=4EA72E}，自备若是普通开环步进，把速度降下来并留足惯量余量{/}
  | {C=4EA72E}C2{/} | {C=4EA72E}DS3225 级 PWM 舵机（25kg 金属齿，270° 版）{/} | {C=4EA72E}4 个{/} | {C=4EA72E}25~35 元/个{/} | {C=4EA72E}Z 轴升降×1 + 夹爪开合×1 + 备件×2。{/}{C=4EA72E}⚠️{/}{C=4EA72E} {/}{C=4EA72E}必须 270° 版{/}{C=4EA72E}（夹爪 v2 需 152.8°）；舵机无反馈 → 靠微动开关到位检测{/}
  | {C=4EA72E}C3{/} | {C=4EA72E}舵机金属摇臂/法兰盘{/} | {C=4EA72E}4{/} | {C=4EA72E}~5 元/个{/} | {C=4EA72E}买舵机常附赠塑料臂；夹爪齿轮要拧在舵机盘上，建议上金属臂（4×M3 顶丝压紧无间隙）{/}
  | C4 | 同步带 GT2/GT3 + 同步轮 〔#1起〕+ {C=EE0000}张紧轮套装{/}〔#1止〕【批注#1】 | 1 套 | 40~60 元 | X/Y 传动；开源资料教训：同步带精度高于齿轮齿条。长度第三批按图定
  | 〔#2起〕{C=EE0000}C5{/} | {C=EE0000}深向（Y）MGN12 线轨 + 滑块{/} | {C=EE0000}导轨 350mm×2 + 滑块 4{/} | {C=EE0000}130~200 元{/} | {C=EE0000}⚠️{/}{C=EE0000} {/}{C=EE0000}深向必须用线轨{/}{C=EE0000}：350 导轨 + 45 滑块只有 305 行程，前探还需滑块悬出 ~14mm —— {/}{C=EE0000}光轴+LM8UU 悬出会掉滚珠，绝对不行{/}{C=EE0000}。滑块可选短款 MGN12C（35）多换 10mm 行程{/}〔#2止〕【批注#2】
  | 〔#3起〕{C=EE0000}C6{/} | {C=EE0000}宽向（X）Ø8 光轴 + {/}{C=EE0000}LM8UU + 支撑座{/} | {C=EE0000}1 套{/} | {C=EE0000}50~80 元{/} | {C=EE0000}宽向行程富余（225 需 176），可用光轴；长度第三批按图定{/}〔#3止〕【批注#3】
  | 〔#4起〕C7 | 同步轮/联轴器与步进轴的配套件 | 2 套 | ~15 元/套 | ⚠️ 按自备步进的轴径（5mm/8mm）下单〔#4止〕【批注#4】
  | 〔#5起〕C8 | 微动开关（限位/触货） | 8 个 | ~1 元/个 | X/Y 原点各 1 + 夹爪触货 1 + Z 低位 1 + 备 4（v2 由 5 个加量到 8 个）〔#5止〕【批注#5】
  | 〔#6起〕C9 | 夹爪增补件（见《夹爪设计参数表.md》§5） | 1 套 | 25~40 元 | ① MF106ZZ 带法兰微型轴承 6×10×3 ×（4+2 备）② Ø6 导杆 ≈44mm ×4 根（v2 每爪 2 根）③ 压簧（预压 3~5N，外径 ≤6、长 10~15，买几种刚度试）④ 爪垫（TPU 打印或 3M 泡棉 2mm）⑤ M1.5 成品齿条 100mm（自打印齿隙大时兜底）。⚠️ 齿轮/齿条一律自打印（100% 填充 + 0.15mm 层高），不买成品套件〔#6止〕【批注#6】
[/TABLE]
D. 传感器（入盒检测）
[TABLE]
  | # | 物品 | 数量 | 参考价 | 备注
  | {C=4EA72E}D1{/} | {C=4EA72E}红外对射对管（发射+接收分体，带 LM393 比较器模块，3.3~5V 数字输出）{/} | {C=4EA72E}6 对（+2 对备）{/} | {C=4EA72E}3~5 元/对 → {/}{C=4EA72E}20~45 元{/} | {C=4EA72E}6 个储物盒各 1 路{/}{C=4EA72E}：规则要求"货物必须全部进入储物盒才计分"，必须有硬件确认。{/}{C=4EA72E}选对射不选漫反射{/}{C=4EA72E}：对射不看货物颜色/反射率（黑色泡沫、带污渍的货都能测），跨盒 82mm 光路足够{/}
  | {C=C00000}D2{/} | {C=C00000}（备选/兜底）低操作力杠杆微动开关{/} | {C=C00000}6（+2 备）{/} | {C=C00000}1~2 元/个{/} | {C=C00000}货落下压住杠杆即计数，{/}{C=C00000}纯机械、颜色无关、更便宜{/}{C=C00000}。{/}{C=C00000}⚠️{/}{C=C00000} 货只有 20~50g，普通微动操作力 50~150gf {/}{C=C00000}可能压不动{/}{C=C00000} → {/}{C=C00000}必须先用真货实测{/}{C=C00000}；选型挑 ≤30gf 的{/}
  | {C=C00000}D3{/} | {C=C00000}（加强，可选）每盒 1 路对射 + {/}{C=C00000}俯视相机复核{/} | {C=C00000}—{/} | {C=C00000}0 元（用已有相机）{/} | {C=C00000}双确认：相机看"该格是否有货"作为软件冗余，防单点失效（规则里"未全入盒不计数"，宁可多一层）{/}
[/TABLE]
{C=333333}⚠️{/}{C=333333} {/}{C=333333}为什么不能用 E18-D80NK（原清单那款）{/}{C=333333}：① 它是 {/}{C=333333}M18 圆柱、长约 60mm{/}{C=333333}，而{/}{C=333333}爪子下潜外廓 71mm 对盒内腔 82mm，单侧只剩 5.5mm{/}{C=333333} → {/}{C=333333}塞不进盒内{/}{C=333333}；② 漫反射最短检测距离 ~3cm，而盒内净空只有 {/}{C=333333}45mm（货 40mm）{/}{C=333333} → 贴脸检测不可靠；③ 漫反射对{/}{C=333333}黑色/低反射货{/}{C=333333}容易失灵。{/}{C=333333}⚠️{/}{C=333333} {/}{C=333333}安装与采样的两条硬要求（要写进建模与状态机）{/}{C=333333}：{/}{C=333333}1. {/}{C=333333}传感器腔做在盒壁"外侧凸台"上{/}{C=333333}（外壁局部加厚 6~8mm 挖腔，对射管贴盒内壁底部离底 5~10mm）——{/}{C=333333}内腔 82 一点不能减{/}{C=333333}（4 件 40mm 货的容量红线）。{/}{C=333333}2. {/}{C=333333}采样时机必须在爪子抬起、离开该盒口之后{/}{C=333333}再读这一路——爪子本身会遮断光路，边放边读会误判。状态机里把"入盒确认"排在"Z 轴抬升 + 横移离开"之后。{/}
E. 显示
[TABLE]
  | # | 物品 | 数量 | 参考价 | 备注
  | 〔#7起〕{C=4EA72E}E1{/} | {C=4EA72E}淘晶驰串口屏 3.5 寸（480×320，USART HMI）{/} | {C=4EA72E}1{/} | {C=4EA72E}60~90 元{/} | {C=4EA72E}规则要求{/}{C=4EA72E}高亮彩屏、能播图片{/}{C=4EA72E}：逐件显示序号/货物名称/图片/成功总数。货物图片预存屏内，串口发指令切换。{/}{C=4EA72E}⚠️{/}{C=4EA72E} 别买成裸 TFT{/}〔#7止〕【批注#7】
[/TABLE]
F. 电源系统（只剩电池与充电器要买）
[TABLE]
  | # | 物品 | 数量 | 参考价 | 备注
  | {C=4EA72E}F1{/} | {C=4EA72E}6S（24V）2200~3000mAh 25C 航模锂电{/} | {C=4EA72E}1 包{/} | {C=4EA72E}180~280 元{/} | {C=4EA72E}格氏 Gens Ace / Tattu {/}{C=4EA72E}品牌官方旗舰店{/}{C=4EA72E}。{/}{C=4EA72E}⚠️{/}{C=4EA72E} 动力头确认 {/}{C=4EA72E}XT60{/}{C=4EA72E} 不是 T 插；规则禁止赛中换电池，单包即可{/}
  | {C=4EA72E}F2{/} | {C=4EA72E}6S 平衡充电器（B6 类）{/} | {C=4EA72E}1{/} | {C=4EA72E}100~150 元{/} | {C=4EA72E}⚠️{/}{C=4EA72E} {/}{C=4EA72E}必买{/}{C=4EA72E}，没它 6S 电池无法充电；确认支持 6S{/}
  | {C=4EA72E}F3{/} | {C=4EA72E}~~低压报警/总开关/保险丝/急停/启动按钮/降压模块/电容/XT60/洞洞板~~{/} | {C=4EA72E}已有或自备{/} | {C=4EA72E}—{/} | {C=4EA72E}见上方"已有"表；核对降压模块能否调到舵机所需电压{/}
[/TABLE]
G. 线材与连接
[TABLE]
  | # | 物品 | 数量 | 参考价 | 备注
  | {C=4EA72E}G1{/} | {C=4EA72E}TRVV 柔性拖链电缆一卷（0.3~0.5mm² 多芯）{/} | {C=4EA72E}1 卷{/} | {C=4EA72E}30~50 元{/} | {C=4EA72E}龙门 X/Y 运动走线反复弯折，{/}{C=4EA72E}必须用拖链电缆{/}{C=4EA72E}。{/}{C=4EA72E}⚠️{/}{C=4EA72E} 国特队 FC 灰排线磨破烧 Jetson 的教训{/}
  | 〔#8起〕G2 | 硅胶导线 18~22AWG | 红黑各若干米 | ~20 元 | 动力回路，耐大电流耐高温〔#8止〕【批注#8】
  | {C=4EA72E}G3{/} | {C=4EA72E}杜邦线 + 排针排母套装{/} | {C=4EA72E}1 套{/} | {C=4EA72E}~15 元{/} | {C=4EA72E}信号连接、调试飞线（若实验室有可省）{/}
  | {C=4EA72E}G4{/} | {C=4EA72E}热缩管套装{/} | {C=4EA72E}1 盒{/} | {C=4EA72E}~10 元{/} | {C=4EA72E}焊点绝缘{/}
  | {C=4EA72E}G5{/} | {C=4EA72E}扎带 + 缠绕管/蛇皮管 + 小型拖链{/} | {C=4EA72E}各 1{/} | {C=4EA72E}~20 元{/} | {C=4EA72E}龙门架理线，防磨防刮{/}
[/TABLE]
H. 结构材料与紧固件
[TABLE]
  | # | 物品 | 数量 | 参考价 | 备注
  | {C=4EA72E}H1{/} | {C=4EA72E}~~铝型材 2020 等~~{/} | {C=4EA72E}已有 4040（量够）{/} | {C=4EA72E}—{/} | {C=4EA72E}按图下料 ≈4.2m；{/}{C=4EA72E}⚠️{/}{C=4EA72E} 另需{/}{C=4EA72E}角件/端面攻丝 M8/中心连接件/T 型螺母{/}{C=4EA72E}，缺了要补{/}
  | {C=4EA72E}H2{/} | {C=4EA72E}玻纤板/亚克力板（底板 + 挡板）{/} | {C=4EA72E}按需{/} | {C=4EA72E}40~60 元{/} | {C=4EA72E}底板 270×350（或 350×350 四角开缺口，详见《框架与布局尺寸.md》§6）；打印件前先切木板验证{/}
  | {C=4EA72E}H3{/} | {C=4EA72E}M3/M4 螺丝螺母垫圈套装{/} | {C=4EA72E}1~2 盒{/} | {C=4EA72E}~20 元/盒{/} | {C=4EA72E}模块化要求"拆任一部件 ≤5 颗螺丝"，备足标准件{/}
  | {C=4EA72E}H4{/} | {C=4EA72E}M3 铜柱（双通/单通混合）{/} | {C=4EA72E}若干{/} | {C=4EA72E}~10 元{/} | {C=4EA72E}主控板、降压模块、传感器架空固定{/}
  | {C=4EA72E}H5{/} | {C=4EA72E}~~3D 打印耗材~~{/} | {C=4EA72E}已有/自备{/} | {C=4EA72E}—{/} | {C=4EA72E}⚠️{/}{C=4EA72E} 确认库存：6 盒 + 托盘 + 夹爪整套 + 支架，用量不小；PLA 优先（齿轮/齿条 100% 填充、0.15mm 层高）{/}
  | {C=4EA72E}H6{/} | {C=4EA72E}木板/KT 板（试切验证用）{/} | {C=4EA72E}若干{/} | {C=4EA72E}~20 元{/} | {C=4EA72E}打正式件前先切木板验证装配{/}
[/TABLE]
I. 工具与耗材
全部已有/自备，不采购。 上电前自检清单：电烙铁（要大功率，焊 XT60）+ 焊锡/吸锡器 · 剥线钳/斜口钳 · 内六角套装 · 热熔胶枪 · 万用表（量各路电压再上电） · 电工胶带/双面胶。
预算估算
[TABLE]
  | 类别 | 小计
  | A 主控 | 35~70 元
  | B 视觉 | 70~120 元
  | C 运动与执行（舵机 + 线轨 + 同步带 + 光轴 + 夹爪增补） | 390~570 元
  | D 传感器 | 30~45 元（对射 6 对 20~45；微动备选更便宜）
  | E 显示 | 60~90 元
  | F 电源（只剩电池 + 充电器） | 280~430 元
  | G 线材与连接 | 95~130 元
  | H 结构材料（板材/标准件） | 90~130 元
  | 合计（工具类不计，已自备） | 约 1050~1600 元
[/TABLE]
{C=333333}相比上一版（1600~2200）省下的是：步进电机（250~330）、铝型材（60~100）、3D 耗材（100~140）、电源杂项（~60）、工具类；新增的是 {/}{C=333333}深向 MGN12 线轨（130~200）{/}{C=333333} 与 {/}{C=333333}夹爪增补件（25~40）{/}{C=333333}。{/}{C=333333}若自备的步进不带驱动器/或需要新驱动器，再追加 2×30~60 元。{/}
下单顺序建议
第一批（立即）：A1 主控、B1+B3 视觉与补光、C2 舵机（270° 版）、F1+F2 电池与充电器 —— 到货周期长，且"让机构动起来/看得见"阶段全要用
第二批（建模前）：C3~C9、D1、E1、G 全部 —— 便宜件一次凑齐省运费
第三批（建模定稿后按图买）：C4 同步带长度、C5 MGN 导轨长度、C6 光轴长度、H2 板材尺寸 —— 长度/规格全部按三维图买

===== Word 批注（comments）=====
[批注 id=0 作者=fulemeichenggong@outlook.com] 需要买带灯罩，24v的
[批注 id=1 作者=fulemeichenggong@outlook.com] 都有什么？
[批注 id=2 作者=fulemeichenggong@outlook.com] 具体参数不清楚
[批注 id=3 作者=fulemeichenggong@outlook.com] 未找到宽向
[批注 id=4 作者=fulemeichenggong@outlook.com] c4不是买了吗？
[批注 id=5 作者=fulemeichenggong@outlook.com] 买这个何意味？
[批注 id=6 作者=fulemeichenggong@outlook.com] 没看懂
[批注 id=7 作者=fulemeichenggong@outlook.com] 已完成
[批注 id=8 作者=fulemeichenggong@outlook.com] 买多长？

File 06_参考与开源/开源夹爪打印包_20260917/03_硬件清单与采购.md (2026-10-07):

# 硬件清单与采购（国内可买）

> 队内资料。原设计 BOM：`参考\SO-ARM夹爪\docs\bom.md`（美元、亚马逊链接）。
> 这里换成**国内能买到的东西 + 人民币估价**，并给出"舵机两条路线"的取舍。

---

## 1 原样复刻清单（推荐）

| # | 件 | 规格 | 数量 | 国内估价 | 备注 |
|:--:|---|---|:--:|---|---|
| A | 总线舵机 | **Feetech STS3215**（12V，堵转 30kg·cm，绝对磁编码） | 1 | ¥210~280 | 淘宝搜"STS3215 总线舵机"；**必须买到带舵盘/螺钉的整包** |
| B | 总线转接板 | **Waveshare Bus Servo Adapter (A)** 或同功能 | 1 | ¥70~95 | USB→TTL 半双工；官方装配第 2 步要用它设 **Max Torque Limit** |
| C | 法兰轴承 | **MF106ZZ 6×10×3（带边）** | 2 | ¥1~2/个 | 主框导杆支撑 |
| D | 导杆 | **Ø6 × 125mm**：碳管 / 铝管 / 铝棒 / 钢棒 **任选一种** | 2 | ¥5~15 | 碳管最轻、钢棒最耐磨；长了自己锯到 125 |
| E | 内六角沉头 | M4×8（DIN 7991） | 2 | 忽略 | 压轴承 |
| F | 内六角 | M2×8（DIN 912） | 2 | 忽略 | 相机固定 |
| G | 螺母 | M2 | 4 | 忽略 | 相机固定 |
| H | 无头紧定 | M3×4（DIN 913） | 4 | 忽略 | 齿轮锁到舵盘 |
| I | 自攻螺钉 | 舵机自带（3 颗装舵机 + 4 颗装支架） | 7 | 舵机自带 | 不够就备 M2.6×8 自攻 |
| J | 降压模块 | 6S → **12V / ≥3A** | 1 | ¥15~25 | STS3215 堵转 2.7A，留余量；我方已有 6S 版降压模块，**确认输出可设 12V** |
| K | 爪垫 | TPU 95A 自打印 ×2，或 **1.5mm 3M 背胶硅胶垫** 剪 70×14 | 2 | ¥0 / ¥5 | 决定抓得稳不稳，见 `05_抓取稳定性.md` |
| — | 3D 打印件 | 包内 STL | 9+2+2 | 约 250g 耗材 | 约 ¥15~25 |
| | **合计** | | | **≈ ¥300 ~ 420** | 官方口径整包 $83 ≈ ¥600（含运费/批量装） |

---

## 2 舵机：两条路线，选一条

| | 路线 A：原样复刻（**推荐**） | 路线 B：复用已买的 DS3225 |
|---|---|---|
| 舵机 | Feetech STS3215（12V 串行总线） | DS3225（PWM，25kg·cm，270°）**已买** |
| 成本 | +¥280~375（舵机+转接板） | ¥0 |
| 工作量 | 0：按官方装配手册装完就能用 | **半天~1 天**：① 量主框舵机腔，确认 40×20×40.5 的 DS3225 塞得进（原腔是按 STS3215 的 ~45×25×35 做的）；② **自画一块"25T 舵盘 → 齿轮"转接件**（齿轮上 4 个 M3 紧定孔是按 STS3215 舵盘打的，标准 25T 舵盘孔位不同）；③ 去掉总线调参步骤，改用 PWM 位置控制 |
| 风险 | 低（设计者验证过） | 中：同轴度与刚性靠自己保证，返工概率不低 |
| 结论 | **验证件走这条**：花 ¥300 换"一定能动"，值 | 只有当"必须复用 DS3225"时才走；**正式件建议直接用我方 v2 夹爪**（本来就是按 DS3225 设计的） |

### 为什么会有这个纠结

我方已购舵机是 **PWM 舵机**，而这套开源夹爪是**串行总线舵机**方案：
总线舵机的好处是能读位置/温度/负载，还能软件限矩（官方装配第 2 步就是把 `Max Torque Limit` 设成 500，
防止把货物和机构夹坏）；代价是要多一块转接板、多一套半双工串口代码。
我们 STM32 有空闲 UART，能做，但"赶工期先跑通"的角度，**买 STS3215 最省事**。

---

## 3 还要自己补的两样（图纸层面）

| 件 | 为什么 | 怎么做 |
|---|---|---|
| **Z 轴→夹爪转接板** | 夹爪接口是 Ø20 法兰 + 4×Ø3.2 孔 + Ø7 中心孔（配 SO-ARM 腕部）；我们是龙门 Z 轴滑块 | 用包内 `安装支架 RB9.01.060.080`（17×48×37）当连接耳，转接板对齐它的 M3 孔位画一块；孔位在 Fusion 里开 `models\RB9.01.062.000 Gripper.STEP` 实量 |
| **相机支架选型** | 整版里给的是"带相机位"的 `060.074 相机支架`；不装相机就用 `060.080 安装支架` 替代（两个都已拆进 `单件\`） | 我方是"相机固定在上方看料盘"，**夹爪上不需要带相机** → 直接不用 060.074/090，改用 060.080 |

---

## 4 下单清单（一句话版）

> **STS3215 总线舵机 ×1 + Waveshare 总线转接板 ×1 + MF106ZZ 轴承 ×2 + Ø6×125 杆 ×2
> + M4×8 沉头 ×2 + M2×8 ×2 + M2 螺母 ×4 + M3×4 紧定 ×4 + 6S→12V 降压 ×1 + PLA+ 与 TPU 耗材**
> 合计 ≈ **¥300~420**（打印件自己打）。

---

## 5 与项目采购清单（`04_采购\采购清单.md`）的接口

| 建议 | 说明 |
|---|---|
| 先不动主清单 | 这份包属于"验证件/参考件"，**不要把 STS3215 写进正式 BOM**，除非拍板"验证件也按原样复刻" |
| 若拍板要做验证件 | 在采购清单里加一行"H7 验证夹爪舵机套装（STS3215 + 转接板 + 轴承 + 导杆）≈ ¥300~420"，并注明"仅验证件、不进提交件" |
| 耗材 | 与待办 H5b（备用耗材 1 卷）合并买；TPU 0.5kg 小卷单独加一行 |

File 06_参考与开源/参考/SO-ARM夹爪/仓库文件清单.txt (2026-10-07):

     2841  .github/workflows/ci.yaml
       69  .gitignore
     1742  .pre-commit-config.yaml
     4114  CLAUDE.md
     4463  CONTRIBUTING.md
    18657  DOCS-LICENSE.txt
     8852  HARDWARE-LICENSE.txt
    11358  LICENSES/Apache-2.0.txt
    18657  LICENSES/CC-BY-4.0.txt
     8852  LICENSES/CERN-OHL-P-2.0.txt
     5392  LICENSING.md
     3637  NOTICE
    12738  README.md
     6359  RELICENSING.md
     7767  REUSE.toml
    11358  SOFTWARE-LICENSE.txt
    92681  assets/images/SO ARM 101 Parallel Gripper Live.jpg
   148022  assets/images/assembly/02-servo-with-gear-assembly.png
   117213  assets/images/assembly/09-gripper-holder-attachment.png
   234940  assets/images/assembly/Feetech-Servo-Window.png
   207478  assets/images/assembly/camera-attachment.png
    75543  assets/images/assembly/clamp+rack+nail.PNG
    76989  assets/images/assembly/clamp+rack.png
   132132  assets/images/assembly/frame+bearings.png
   167906  assets/images/assembly/frame-with-clamps.png
   250188  assets/images/assembly/max-torque-window.png
    39609  assets/images/assembly/rod-test-plate.PNG
   126136  assets/images/assembly/rods+clamps.PNG
   204629  assets/images/assembly/servo-on-frame.png
   139145  assets/images/simulation/gazebo/gazebo_pick_place.png
   134316  assets/images/simulation/mujoco/mujoco_pick_place.png
   165260  assets/images/specification/03-mounting-interface.jpg
   147829  assets/images/specification/07-gripper-on-so-arm100.jpg
   139686  assets/images/specification/08-gripper-dimensions-3d.png
   443971  assets/images/specification/09-camera-types.png
     4579  community/histology-slide-gripper/README.md
    45324  community/histology-slide-gripper/assets/arducam-holder-front.jpg
 25652874  community/histology-slide-gripper/assets/histology-slide-gripper-demo.gif
    75131  community/histology-slide-gripper/assets/parallel-microscope-gripper-front.png
   196249  community/histology-slide-gripper/assets/parallel-microscope-gripper-isometric.png
   100141  community/histology-slide-gripper/assets/parallel-microscope-gripper-side.png
    53224  community/histology-slide-gripper/assets/slide-gripper-single-slide.jpg
    63992  community/histology-slide-gripper/assets/slide-gripper-staining-dipper.jpg
  2976973  community/histology-slide-gripper/cad/the-parallel-microscope-slide-gripper.step
  2521584  community/histology-slide-gripper/cad/the-parallel-microscope-slide-gripper.stl
       59  community/histology-slide-gripper/mujoco/.gitignore
     7228  community/histology-slide-gripper/mujoco/README.md
     1777  community/histology-slide-gripper/mujoco/build_arm.py
     4704  community/histology-slide-gripper/mujoco/build_full.py
      900  community/histology-slide-gripper/mujoco/gripper_actuation.xml
      844  community/histology-slide-gripper/mujoco/gripper_assets.xml
     2992  community/histology-slide-gripper/mujoco/gripper_body.xml
  1456384  community/histology-slide-gripper/mujoco/meshes/arm/base_link.stl
   440484  community/histology-slide-gripper/mujoco/meshes/arm/clamp_1.stl
   440484  community/histology-slide-gripper/mujoco/meshes/arm/clamp_2.stl
  1669384  community/histology-slide-gripper/mujoco/meshes/arm/link1_1.stl
  1437284  community/histology-slide-gripper/mujoco/meshes/arm/link2_1.stl
  1857784  community/histology-slide-gripper/mujoco/meshes/arm/link3_1.stl
  2032084  community/histology-slide-gripper/mujoco/meshes/arm/link4_1.stl
  2239584  community/histology-slide-gripper/mujoco/meshes/arm/link5_1.stl
  1271184  community/histology-slide-gripper/mujoco/meshes/base.stl
    69584  community/histology-slide-gripper/mujoco/meshes/jaw_left.stl
    69584  community/histology-slide-gripper/mujoco/meshes/jaw_right.stl
   287884  community/histology-slide-gripper/mujoco/meshes/pinion.stl
   183219  community/histology-slide-gripper/mujoco/mujoco_simulation_preview.png
      990  community/histology-slide-gripper/mujoco/render_arm.py
     1504  community/histology-slide-gripper/mujoco/render_link5.py
       40  community/histology-slide-gripper/mujoco/requirements.txt
     1876  community/histology-slide-gripper/mujoco/scene_gripper.xml
     4963  community/histology-slide-gripper/mujoco/so101_slide_gripper.xml
    11242  community/histology-slide-gripper/mujoco/so_101.urdf.xacro
     7037  community/histology-slide-gripper/mujoco/so_101_arm.urdf
     3332  community/histology-slide-gripper/mujoco/so_101_arm.xml
     1579  community/histology-slide-gripper/mujoco/test_grasp.py
      566  community/histology-slide-gripper/mujoco/view.py
   660315  docs/Assembly Guide Follower Gripper.pdf
   674475  docs/Assembly Guide SO-ARM101.pdf
   167026  docs/Parallel gripper by Robo9.pdf
   310453  docs/SO-ARM101 by Robo9.pdf
     5099  docs/assembly-guide.md
     4018  docs/bom.md
     4922  docs/quick-start.md
     4336  docs/specifications.md
     2456  examples/README.md
     2762  examples/basic_usage.py
   534184  models/Follower gripper (165x165 bed size).STL
  5731780  models/RB9.01.062.000 Gripper.STEP
     2512  models/README.md
   204284  models/parts/Gripper test plate star holes 6.0-6.3.STL
   145184  models/parts/RB9.01.060.074 Camera holder.STL
    82584  models/parts/RB9.01.060.080 Holder.STL
    41284  models/parts/RB9.01.060.090 Camera spacer.STL
   268084  models/parts/RB9.01.060.110 D405 holder.STL
    90284  models/parts/RB9.01.062.010 Main frame.STL
    37784  models/parts/RB9.01.062.020 Clamp.STL
    73484  models/parts/RB9.01.062.021 (D6.0) Clamp.STL
    73484  models/parts/RB9.01.062.021 (D6.1) Clamp.STL
    73484  models/parts/RB9.01.062.021 (D6.2) Clamp.STL
    73484  models/parts/RB9.01.062.021 (D6.3) Clamp.STL
    22084  models/parts/RB9.01.062.030 Gear rack.STL
    23584  models/parts/RB9.01.062.031 Gear rack.STL
    55784  models/parts/RB9.01.062.040 Gear.STL
     2684  models/parts/RB9.01.062.100 Nail.STL
     5588  simulation/README.md
     3558  simulation/coppeliasim/README.md
     1985  simulation/gazebo/README.md
     3274  simulation/isaac_sim/README.md
     2545  simulation/mujoco/README.md
      109  simulation/so_arm_101_description/.dockerignore
     5763  simulation/so_arm_101_description/Dockerfile
     1702  simulation/so_arm_101_description/LICENSE.md
      904  simulation/so_arm_101_description/config/controllers.yaml
     4768  simulation/so_arm_101_description/config/display.rviz
     4099  simulation/so_arm_101_description/docker-compose.yaml
      553  simulation/so_arm_101_description/docker/constrain-window.sh
     1310  simulation/so_arm_101_description/docker/entrypoint.sh
     1283  simulation/so_arm_101_description/launch/display.launch.py
     8611  simulation/so_arm_101_description/launch/sim.launch.py
     2221  simulation/so_arm_101_description/meshes/LICENSE.md
    63384  simulation/so_arm_101_description/meshes/collision/base_link.stl
    26084  simulation/so_arm_101_description/meshes/collision/clamp_1.stl
    25884  simulation/so_arm_101_description/meshes/collision/clamp_2.stl
    94184  simulation/so_arm_101_description/meshes/collision/link1_1.stl
   108484  simulation/so_arm_101_description/meshes/collision/link2_1.stl
   153584  simulation/so_arm_101_description/meshes/collision/link3_1.stl
   146684  simulation/so_arm_101_description/meshes/collision/link4_1.stl
    54284  simulation/so_arm_101_description/meshes/collision/link5_1.stl
  1456384  simulation/so_arm_101_description/meshes/visual/base_link.stl
   440484  simulation/so_arm_101_description/meshes/visual/clamp_1.stl
   440484  simulation/so_arm_101_description/meshes/visual/clamp_2.stl
  1669384  simulation/so_arm_101_description/meshes/visual/link1_1.stl
  1437284  simulation/so_arm_101_description/meshes/visual/link2_1.stl
  1857784  simulation/so_arm_101_description/meshes/visual/link3_1.stl
  2032084  simulation/so_arm_101_description/meshes/visual/link4_1.stl
  2239584  simulation/so_arm_101_description/meshes/visual/link5_1.stl
     1815  simulation/so_arm_101_description/package.xml
        0  simulation/so_arm_101_description/resource/so_arm_101_description
     1425  simulation/so_arm_101_description/scripts/generate_collision_meshes.py
     4918  simulation/so_arm_101_description/scripts/publish_mujoco_description.py
     4415  simulation/so_arm_101_description/scripts/setup_webots.py
      665  simulation/so_arm_101_description/scripts/validate_xml.py
      113  simulation/so_arm_101_description/setup.cfg
     1388  simulation/so_arm_101_description/setup.py
        0  simulation/so_arm_101_description/so_arm_101_description/__init__.py
     4918  simulation/so_arm_101_description/so_arm_101_description/publish_mujoco_description.py
     2231  simulation/so_arm_101_description/test/test_config.py
     1462  simulation/so_arm_101_description/test/test_meshes.py
     2743  simulation/so_arm_101_description/test/test_mujoco_load.py
     4576  simulation/so_arm_101_description/test/test_urdf_structure.py
      185  simulation/so_arm_101_description/urdf/materials.xacro
     4110  simulation/so_arm_101_description/urdf/so_101.ros2_control.xacro
    11242  simulation/so_arm_101_description/urdf/so_101.urdf.xacro
     1497  simulation/so_arm_101_description/worlds/empty.sdf
      633  simulation/so_arm_101_description/worlds/webots_world.wbt
     2683  simulation/webots/README.md
    13832  software/python/gripper_control.py
      990  software/python/requirements.txt
# 共 157 个文件，合计 66.85 MB

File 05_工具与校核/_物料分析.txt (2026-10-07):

# 工创赛物料照片分析（自动生成，勿手改）

源目录：工创赛物料/  共 20 张

## 表1 逐张轮廓（像素量，仅用于相对比较）

| 颜色 | 形状 | 像素面积 | 外接矩形 W×H | H/W | 最小外接矩形 长×宽 | 填充率 | 占图比 | H中位 | S中位 | V中位 |
|---|---|---|---|---|---|---|---|---|---|---|
| 绿 | 圆柱 | 141139 | 397×458 | 1.15 | 458×394 | 0.78 | 6.47% | 86 | 249 | 194 |
| 绿 | 正三棱柱 | 97334 | 368×447 | 1.21 | 426×373 | 0.61 | 4.46% | 82 | 247 | 183 |
| 绿 | 正五棱锥 | 108952 | 357×426 | 1.19 | 411×362 | 0.73 | 4.99% | 84 | 248 | 184 |
| 绿 | 正六棱柱 | 147686 | 403×485 | 1.20 | 471×405 | 0.78 | 6.77% | 85 | 249 | 204 |
| 绿 | 正四棱锥 | 91038 | 363×341 | 0.94 | 325×297 | 0.94 | 4.17% | 80 | 249 | 134 |
| 绿 | 正四面体 | 55250 | 347×323 | 0.93 | 348×311 | 0.51 | 2.53% | 80 | 246 | 151 |
| 绿 | 正方体 | 203604 | 542×593 | 1.09 | 504×496 | 0.81 | 9.33% | 85 | 248 | 202 |
| 蓝 | 圆柱 | 165542 | 426×504 | 1.18 | 501×421 | 0.78 | 7.59% | 100 | 146 | 233 |
| 蓝 | 正三棱柱 | 116926 | 396×476 | 1.20 | 468×396 | 0.63 | 5.36% | 101 | 149 | 236 |
| 蓝 | 正五棱锥 | 150522 | 406×510 | 1.26 | 494×409 | 0.74 | 6.90% | 100 | 148 | 236 |
| 蓝 | 正六棱柱 | 146878 | 430×460 | 1.07 | 459×429 | 0.75 | 6.73% | 100 | 151 | 228 |
| 蓝 | 正四棱锥 | 137508 | 436×422 | 0.97 | 398×366 | 0.94 | 6.30% | 101 | 156 | 197 |
| 蓝 | 正四面体 | 70438 | 387×377 | 0.97 | 387×350 | 0.52 | 3.23% | 102 | 153 | 194 |
| 黄 | 圆柱 | 54206 | 393×259 | 0.66 | 392×255 | 0.54 | 2.48% | 32 | 176 | 145 |
| 黄 | 正三棱柱 | 77196 | 442×560 | 1.27 | 709×245 | 0.44 | 3.54% | 20 | 70 | 136 |
| 黄 | 正五棱锥 | 42200 | 391×308 | 0.79 | 416×251 | 0.40 | 1.93% | 32 | 184 | 127 |
| 黄 | 正六棱柱 | 55628 | 514×407 | 0.79 | 501×405 | 0.27 | 2.55% | 32 | 167 | 139 |
| 黄 | 正四棱锥 | 90078 | 297×668 | 2.25 | 668×294 | 0.46 | 4.13% | 20 | 66 | 101 |
| 黄 | 正四面体 | 58953 | 429×408 | 0.95 | 449×337 | 0.39 | 2.70% | 34 | 149 | 168 |
| 黄 | 正方体 | 57992 | 532×352 | 0.66 | 531×348 | 0.31 | 2.66% | 33 | 169 | 145 |

## 表2 按形状汇总（三色取平均）

| 形状 | 张数 | H/W 均值 | H/W 极差 | 填充率 均值 | 判定 |
|---|---|---|---|---|---|
| 正四棱锥 | 3 | 1.39 | 1.31 | 0.78 | 高瘦←→扁矮 |
| 正三棱柱 | 3 | 1.23 | 0.06 | 0.56 | 高瘦←→扁矮 |
| 正五棱锥 | 3 | 1.08 | 0.47 | 0.63 | 高瘦←→扁矮 |
| 正六棱柱 | 3 | 1.02 | 0.41 | 0.60 | 高瘦←→扁矮 |
| 圆柱 | 3 | 1.00 | 0.52 | 0.70 | 高瘦←→扁矮 |
| 正四面体 | 3 | 0.95 | 0.04 | 0.47 | 高瘦←→扁矮 |
| 正方体 | 2 | 0.88 | 0.43 | 0.56 | 高瘦←→扁矮 |

## 表3 颜色标定（HSV，OpenCV 口径 H:0~179 / S,V:0~255）

| 颜色 | 张数 | H 中位 | H 5%~95% | S 中位 | V 中位 | 建议识别窗 |
|---|---|---|---|---|---|---|
| 绿 | 7 | 83 | 77~85 | 248 | 179 | H 71~90 & S≥188 & V≥108 |
| 黄 | 7 | 29 | 22~31 | 140 | 137 | H 16~36 & S≥80 & V≥67 |
| 蓝 | 6 | 101 | 100~104 | 150 | 221 | H 93~109 & S≥90 & V≥150 |

## 表4 完整度（3 色 × 7 形状 = 21 应到）

| 形状 | 绿 | 黄 | 蓝 |
|---|---|---|---|
| 正四棱锥 | ✅ | ✅ | ✅ |
| 正三棱柱 | ✅ | ✅ | ✅ |
| 正五棱锥 | ✅ | ✅ | ✅ |
| 正六棱柱 | ✅ | ✅ | ✅ |
| 圆柱 | ✅ | ✅ | ✅ |
| 正四面体 | ✅ | ✅ | ✅ |
| 正方体 | ✅ | ✅ | ❌ |

实到 20 张；形状 7 种。缺失：蓝-正方体

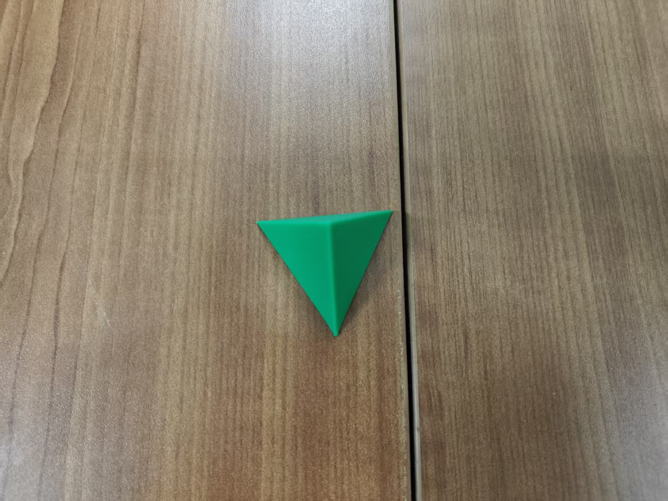
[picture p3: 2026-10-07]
工创赛物料/绿色-正四面体.jpg

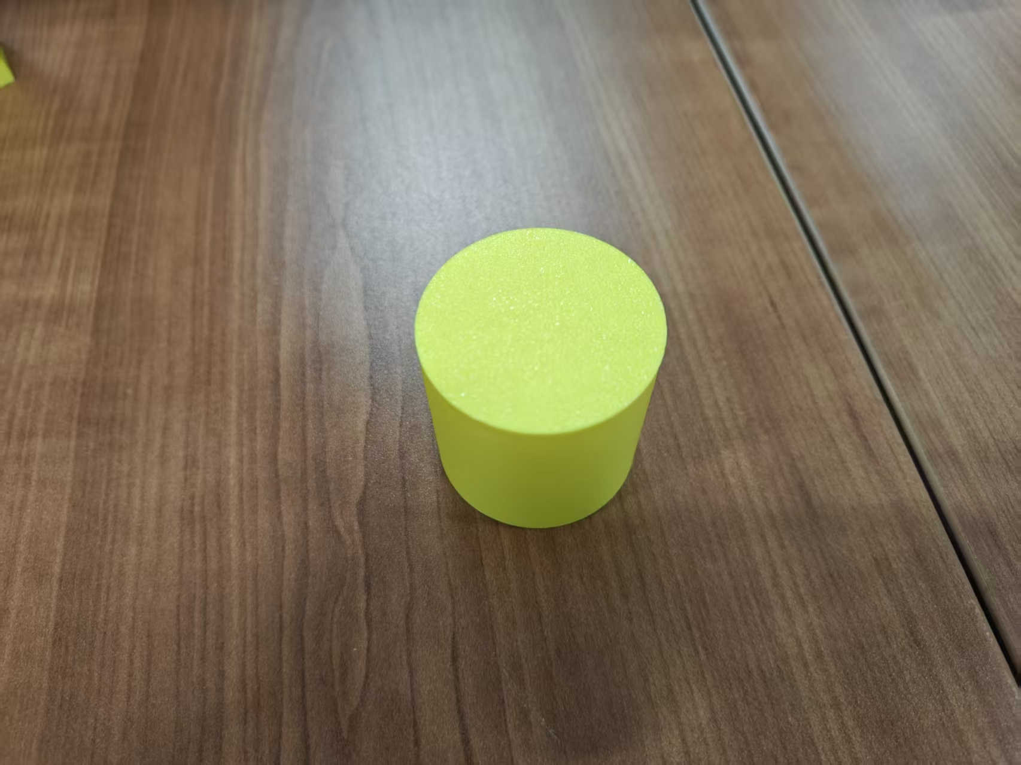
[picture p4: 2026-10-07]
工创赛物料/黄色-圆柱.jpg

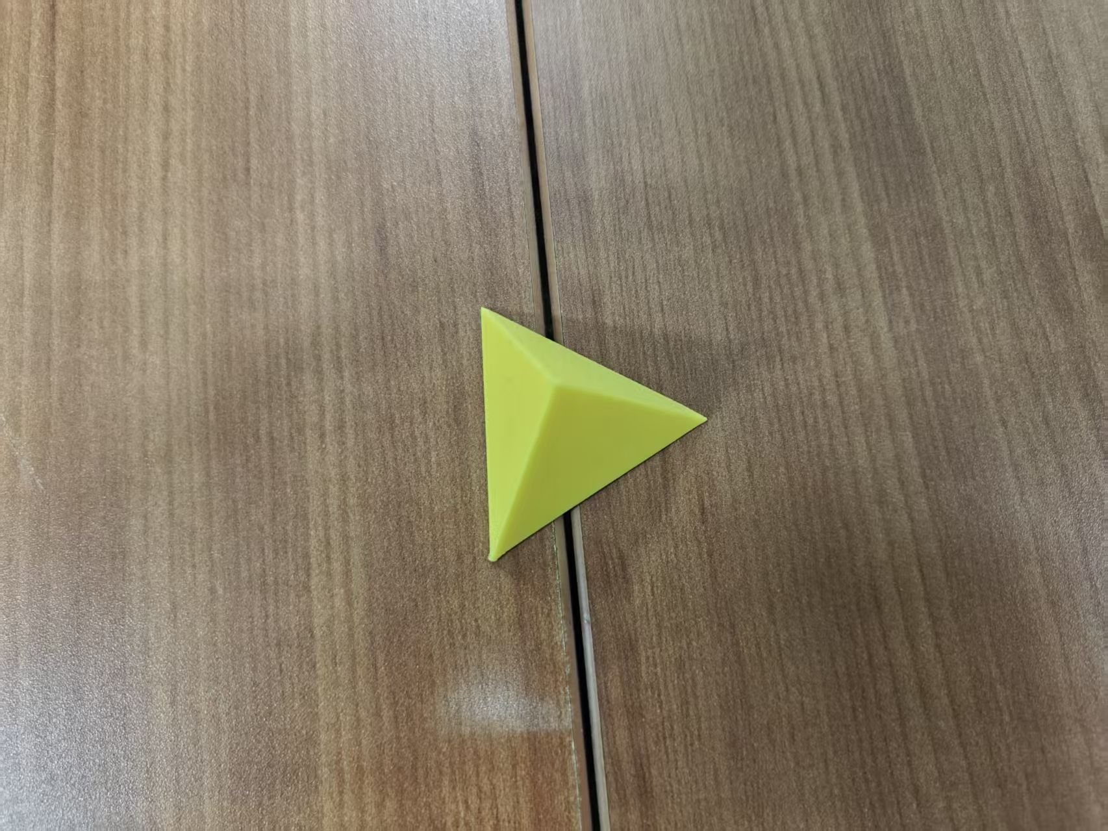
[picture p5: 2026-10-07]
工创赛物料/黄色-正四面体.jpg

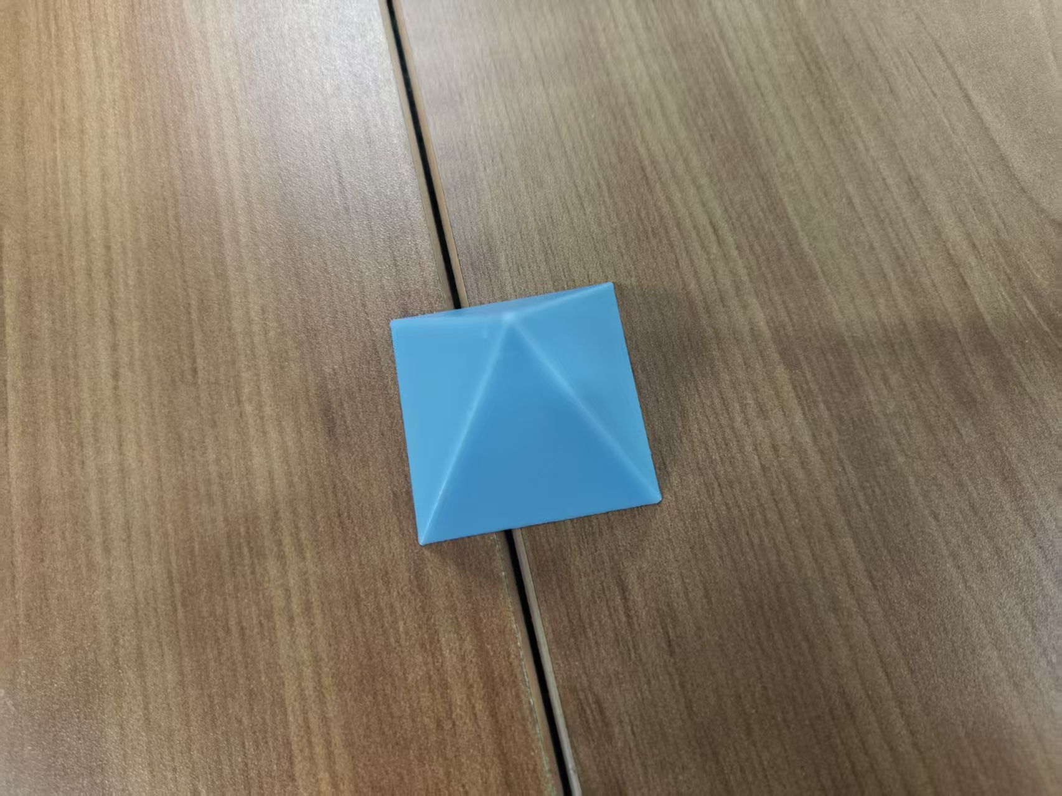
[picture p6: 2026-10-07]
工创赛物料/蓝色-正四棱锥.jpg

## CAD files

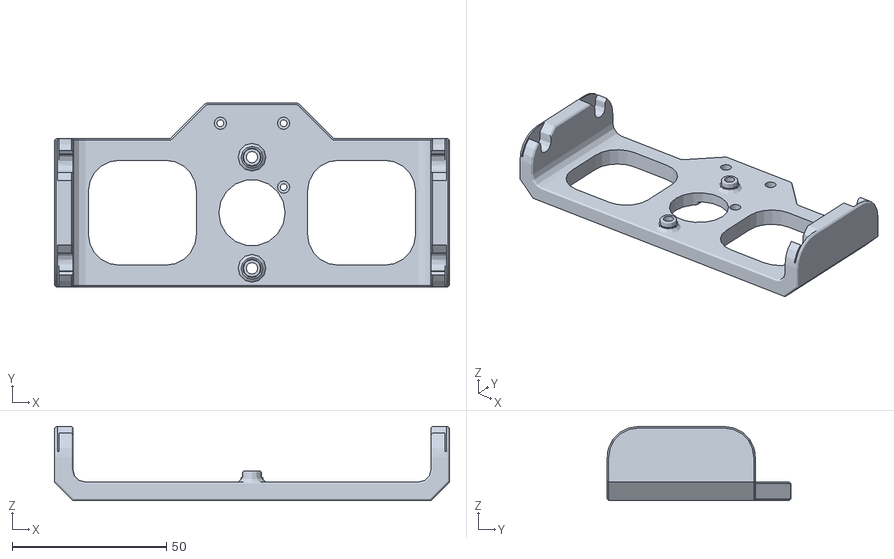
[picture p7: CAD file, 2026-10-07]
06_参考与开源/参考/SO-ARM夹爪/models/parts/RB9.01.062.010 Main frame.STL
128.0 x 59.5 x 24.0

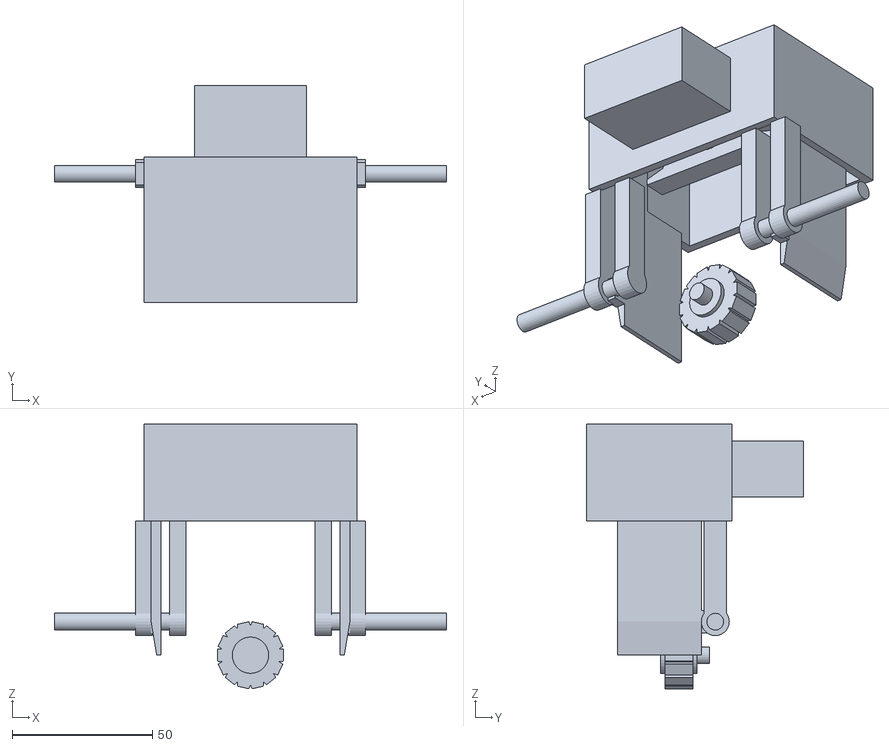
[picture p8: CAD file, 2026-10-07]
03_设计与尺寸/夹爪/stl/夹爪总成.stl
140.0 x 77.5 x 94.5

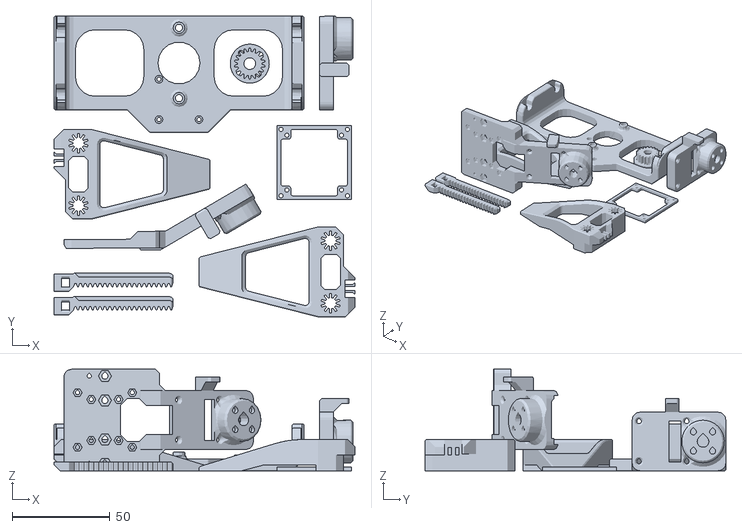
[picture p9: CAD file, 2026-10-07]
06_参考与开源/参考/SO-ARM夹爪/models/Follower gripper (165x165 bed size).STL
154.1 x 154.0 x 52.0

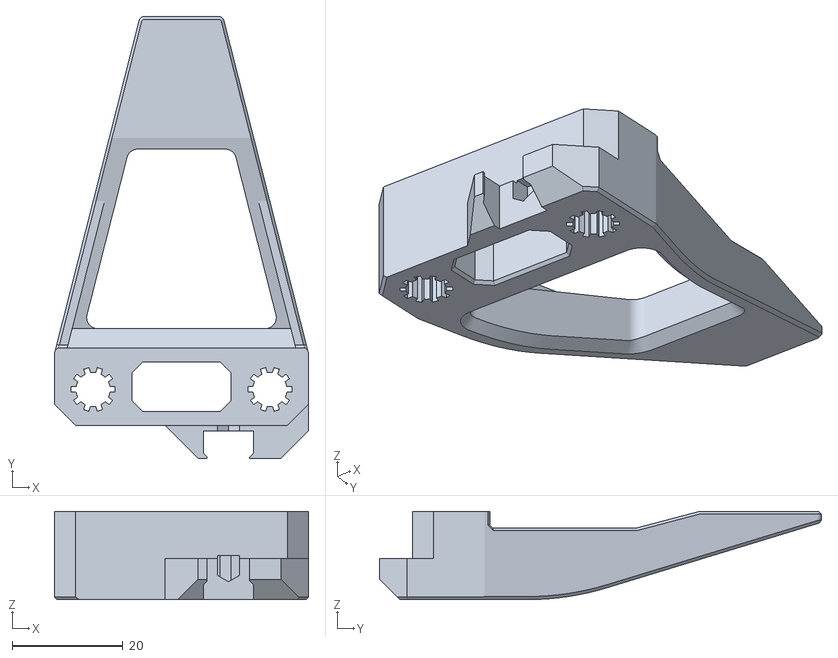
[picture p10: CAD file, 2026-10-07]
06_参考与开源/参考/SO-ARM夹爪/models/parts/RB9.01.062.021 (D6.2) Clamp.STL
46.0 x 80.0 x 16.0

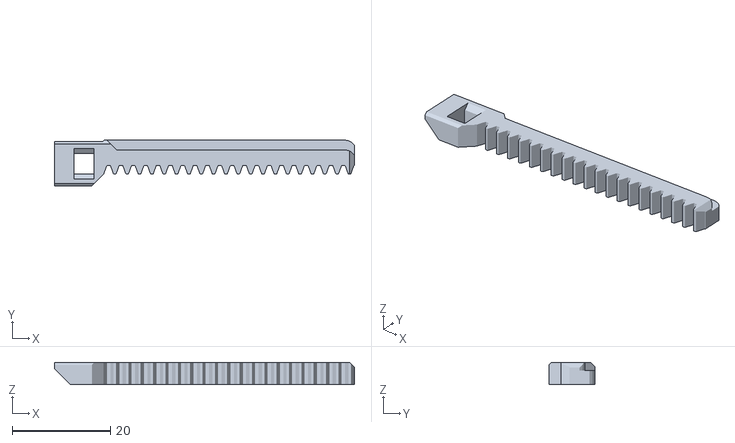
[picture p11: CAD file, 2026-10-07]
06_参考与开源/开源夹爪打印包_20260917/01_打印文件/单件/RB9.01.062.030_齿条_x2.stl
61.0 x 9.35 x 4.50

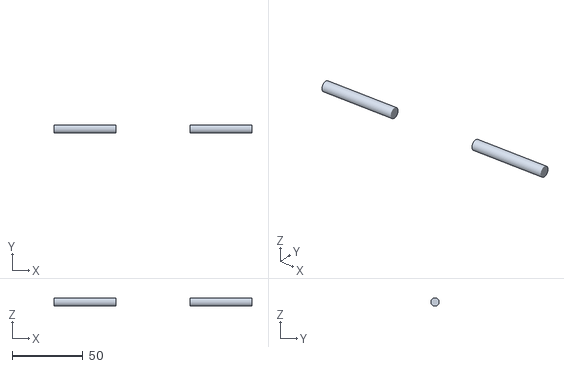
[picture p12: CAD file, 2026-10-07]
03_设计与尺寸/夹爪/stl/导杆 Ø6.stl
140.0 x 6.00 x 6.00

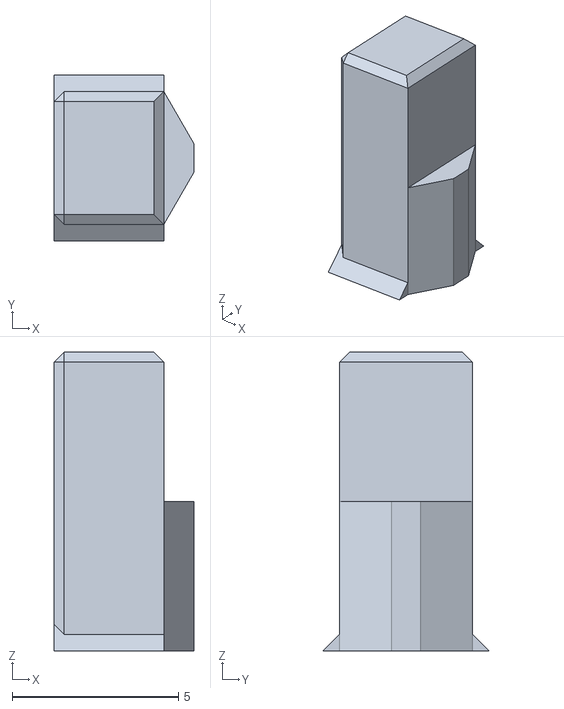
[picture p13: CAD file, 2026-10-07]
06_参考与开源/参考/SO-ARM夹爪/models/parts/RB9.01.062.100 Nail.STL
4.20 x 5.00 x 9.00

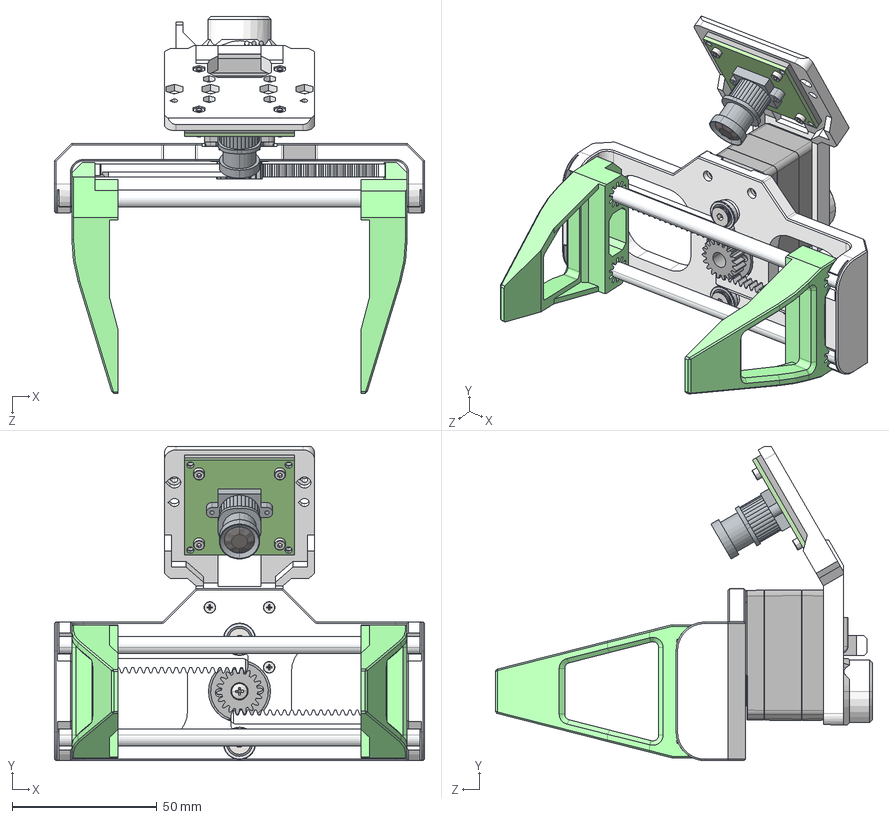
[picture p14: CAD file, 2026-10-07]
06_参考与开源/参考/SO-ARM夹爪/models/RB9.01.062.000 Gripper.STEP
128.0 x 108.8 x 130.5 mm
RB9.01.062.010 Main frame_125 follower
RB9.01.062.020 Clamp x 2
RB9.01.062.030 Gear rack_m0.8 x 2
RB9.01.062.040 Gear for gripper_ISO - Spur gear 0.8M 18T 20PA 5FW ---S18B10H8L6.0S1
RB9.01.062.070 Camera holder_follower + camera
RB9.01.060.090 Camera spacer
Rod d6_125 x 2
ZK_122^STS3215_Servo
SG-ZIJI_15^STS3215_Servo
XG-ZIJI_16^STS3215_Servo
Main Wheel^STS3215_Servo
pan head cross recess screw_din_DIN EN ISO 7045 - M3 x 4 - Z - 4N
0050375033_｢ｯ燿｢ｮ
GC2093 2MP USB Camera Module_IMX335 5MP USB Camera
Bearing_MF106 10å6å3 x 2
countersunk flat head cross recess screw_din_DIN EN ISO 7046-1 - M2 x 8 - Z - 8N x 3
socket countersunk head screw_din_DIN 7991 - M4 x 8 --- 8N x 2
hex nut style 1 gradeab_din_Hexagon Nut ISO 4032 - M2 - D - N x 4
socket head cap screw_din_DIN 912 M2 x 8 --- 8N x 4

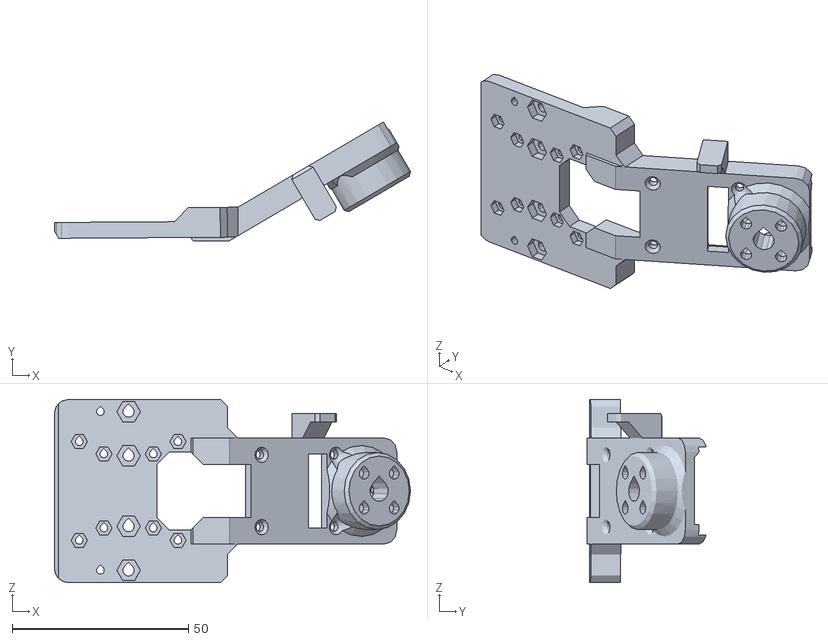
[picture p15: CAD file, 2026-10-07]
06_参考与开源/开源夹爪打印包_20260917/01_打印文件/单件/RB9.01.060.074_相机支架.stl
100.9 x 33.8 x 52.0

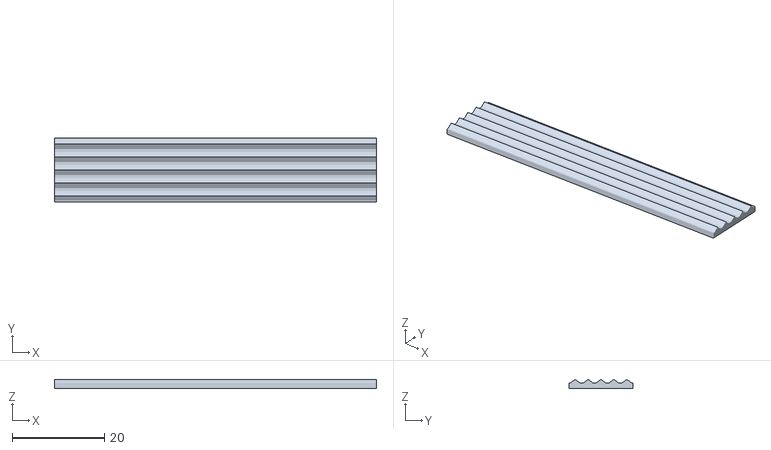
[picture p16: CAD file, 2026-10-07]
06_参考与开源/开源夹爪打印包_20260917/01_打印文件/爪垫_锯齿_70x14x2.stl
70.0 x 14.0 x 2.00

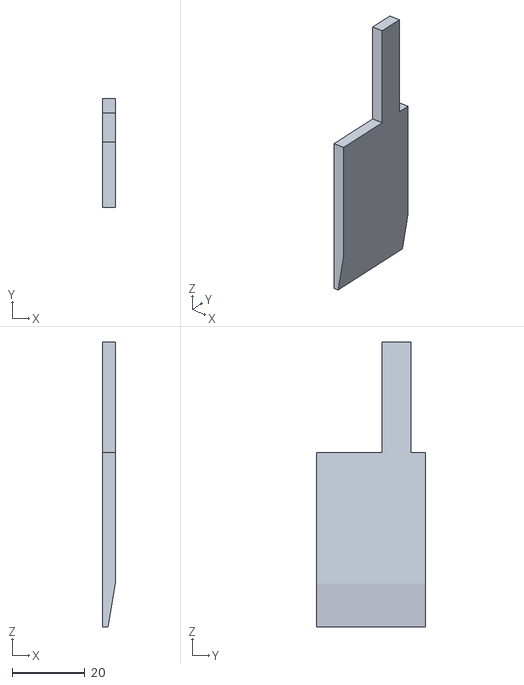
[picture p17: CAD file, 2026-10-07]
03_设计与尺寸/夹爪/stl/爪板-右.stl
3.50 x 30.0 x 78.5

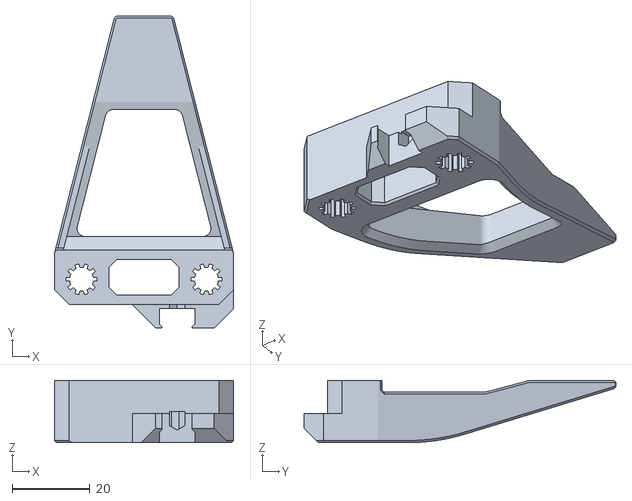
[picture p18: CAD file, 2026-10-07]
06_参考与开源/参考/SO-ARM夹爪/models/parts/RB9.01.062.021 (D6.1) Clamp.STL
46.0 x 80.0 x 16.0

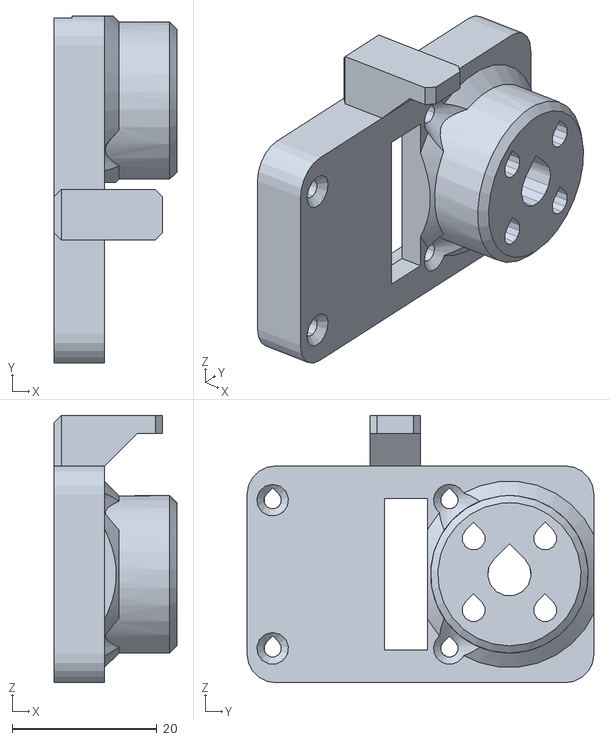
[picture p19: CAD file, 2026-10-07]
06_参考与开源/开源夹爪打印包_20260917/01_打印文件/单件/RB9.01.060.080_安装支架.stl
17.0 x 48.0 x 37.0

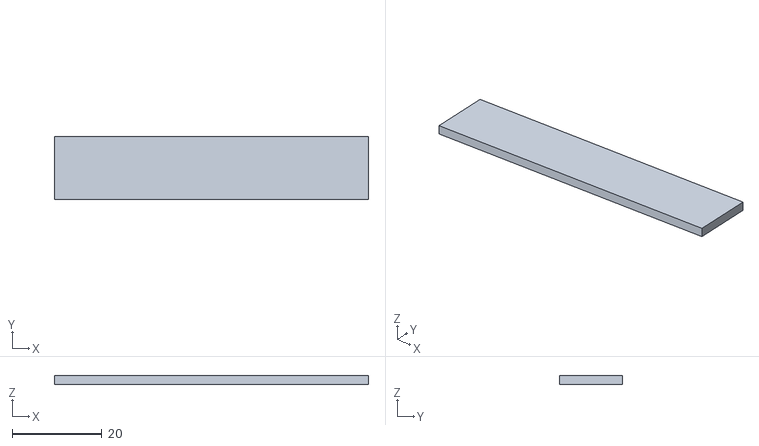
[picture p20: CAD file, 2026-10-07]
06_参考与开源/开源夹爪打印包_20260917/01_打印文件/爪垫_平面_70x14x2.stl
70.0 x 14.0 x 2.00

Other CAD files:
_work/kit_parts/Follower gripper (165x16_08_61x9x5.stl
_work/kit_parts/Follower gripper (165x16_07_38x38x2.stl
_work/kit_parts/Follower gripper (165x16_02_101x34x52.stl
03_设计与尺寸/夹爪/stl/主框.stl
03_设计与尺寸/夹爪/stl/导杆吊耳+轴承.stl
03_设计与尺寸/夹爪/stl/爪板-左.stl
03_设计与尺寸/夹爪/stl/爪板连接耳.stl
03_设计与尺寸/夹爪/stl/舵机 DS3225.stl
03_设计与尺寸/夹爪/stl/齿条-上(右爪).stl
03_设计与尺寸/夹爪/stl/齿条-下(左爪).stl
03_设计与尺寸/夹爪/stl/齿轮 M1.5-z14.stl
06_参考与开源/参考/SO-ARM夹爪/models/parts/Gripper test plate star holes 6.0-6.3.STL
06_参考与开源/参考/SO-ARM夹爪/models/parts/RB9.01.060.074 Camera holder.STL
06_参考与开源/参考/SO-ARM夹爪/models/parts/RB9.01.060.080 Holder.STL
06_参考与开源/参考/SO-ARM夹爪/models/parts/RB9.01.060.090 Camera spacer.STL
06_参考与开源/参考/SO-ARM夹爪/models/parts/RB9.01.060.110 D405 holder.STL
06_参考与开源/参考/SO-ARM夹爪/models/parts/RB9.01.062.020 Clamp.STL
06_参考与开源/参考/SO-ARM夹爪/models/parts/RB9.01.062.021 (D6.0) Clamp.STL
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

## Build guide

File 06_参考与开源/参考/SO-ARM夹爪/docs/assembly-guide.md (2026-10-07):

# Assembly Guide for Follower Gripper SO-ARM101

This guide provides step-by-step instructions for assembling the parallel gripper. Follow these steps carefully to ensure proper operation.

## Required Tools

- Phillips head screwdriver PH1
- Hex keys M2 (H1.5) and M4 (H2.5)

---

## Step 1: Install Gear on Servo

Servo with gear assembly

**Components needed:**
- 1x Feetech STS3215 Servo
- 1x Gear  (RB9.01.062.040)
- 1x Servo disk (from servo kit)
- 1x Servo mounting screw M3x6 (from servo kit)
- 4x Set Screw DIN 913 M3x4

**Instructions:**
1. Place Gear for Gripper on Servo disk and tighten 4x Set Screws M3x4 in the direction from Servo disk to Gear. Make sure that no gap appears between Disk and Gear when tightening the screws.
2. Mount the gear assembly onto the servo output shaft.
3. Secure with the screw M3x6 provided in the servo kit.

---

## Step 2: Servo Positioning and Torque Limit

Servo positioning

**Components needed:**
- 1x Serial Bus Servo Board and Cables

**Instructions for Windows users:**
1. Connect Servo to Serial Bus Servo Board, connect Board to PC by USB.
2. Configure the servo with Feetech's **FD** (SCServo Debug) tool. It is closed-source
   Windows software from Feetech and is **not** redistributed in this repository:
   - Official download: <https://www.feetechrc.com/software.html> — look for the FD /
     SCServo Debug archive. Some downloads there are password-protected; request the
     password from Feetech.
   - Open-source cross-platform alternative:
     <https://github.com/Kotakku/FT_SCServo_Debug_Qt>

   The steps below describe the FD interface; the alternative exposes the same
   parameters under similar names.
3. Choose your COM port, select BaudRate 1 000 000, push buttons "Open" and after "Search".
4. Below from the list select your servo.
5. Check the box to enable torque on servo.
6. Move the slider to the left.

Max torque limit

7. Switch the window to a tab "Programming".
8. Choose parameter "Max Torque Limit", set it to 500 ans press "Save".

---

## Step 3: Clamps

Clamps

**Components needed:**
- 2x Clamps (RB9.01.062.021)
- 2x Gear racks (RB9.01.062.031)
- 2x Nails (RB9.01.062.100)

**Instructions:**
1. Insert gear racks in clamps from side direction.
2. Then insert nails from back direction.

---

## Step 4: Rods

Rods

**Components needed:**
- 2x Rods D6x125mm

**Instructions:**
1. Insert the rods into both clamps. If you ordered rods/tubes longer than 125 mm you need to cut them to this length.

---

## Step 5: Install Bearings on Main Frame

Bearings installed on main frame

**Components needed:**
- 2x MF106ZZ Bearings (10x6x3 mm)
- 2x M4x8 DIN 7991 screws

**Instructions:**
1. Insert the 2x MF106ZZ bearings into their designated positions on the main frame. Bearing flange should face up.
2. Secure each bearing with screw M4x8.

---

## Step 6: Connection of rods and frame

Connection of rods and main frame

**Instructions:**
1. Snap the rods into the frame.
2. Spread the clamps to the extreme positions on the left and right.

---

## Step 7: Mount Servo on Main Frame

Servo mounted on main frame

**Components needed:**
- 3x Self-tapping screws (from servo kit)

**Instructions:**
1. Position the servo on the main frame and align mounting holes.
2. Secure the servo using 3x self-tapping screws from the servo kit.

---

## Step 8: Gripper Holder Attachment

Gripper holder attachment

**Components needed:**
- 1x Camera holder (RB9.01.060.074) or Holder (RB9.01.060.080)
- 1x SO-ARM101
- 4x M3x6 Screws (from servo kit)
- 4x Self-tapping screws (from servo kit)

**Instructions:**
1. If you plan to use Gripper with camera then attach Camera holder, if you plan to use Gripper without camera then attach Holder to the Wrist Joint horn of SO-ARM101 and fix with 4x M3x6 screws
2. Attach the Parallel Gripper to the Camera holder or Holder and fix with 4x self-tapping screws
3. Connect cable from the Parallel Gripper to servo №5 of SO-ARM101

---

## Step 9: Camera Attachment (optional)

Camera attachment

**Components needed:**
- 1x UVC Camera with mount holes at 28x28 mm
- 1x Camera Spacer (RB9.01.060.090)
- 4x M2x8 Screws
- 4x M2 Nuts

**Instructions:**
1. Put 4x nuts M2 from the back side of Camera Holder.
2. Put Camera Spacer and Camera from the front side and fix with 4x screws M2x8.

---
## Assembly Complete!

Assembled SO-ARM101 with Follower Gripper

Congratulations! Your SO-ARM101 is now assembled and ready for use.

### Next Steps
- Test gripper operation before use

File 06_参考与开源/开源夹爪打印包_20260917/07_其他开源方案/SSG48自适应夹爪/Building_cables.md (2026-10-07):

## MSG & SSG48 gripper cable

Buy Official cables from Source Robotics: [Link](https://source-robotics.com/)

Parts needed if DIY your own cable:

| Type | Length / Spec | Quantity | Description | Link |
|---|---|---|---|---|
| 26 AWG cable | 0.15 mm², 4-wire twisted pair | 0.4 m | ~40 cm usually sufficient | [Link](https://s.click.aliexpress.com/e/_c4m3ggwn) |
| M8 4-pin male wire connector | — | 1 | [See reference image](../Photos/M8%20male.png) |[Link](https://s.click.aliexpress.com/e/_c4OWHPKF) |
| M8 4-pin female wire connector | — | 1 | [See reference image](../Photos/M8_female.png) | [Link](https://s.click.aliexpress.com/e/_c4OWHPKF) |

> [!NOTE]
>     **PAROL6 and PAR6 use different cables for SSG48 and MSG grippers. Using incorrect one can damage your robot**

## Wire diagram for PAROL6 robotic arm



## Wire diagram for PAR6 robotic arm


## Final look of the cable 

End result of this cable assembly needs to look like this:



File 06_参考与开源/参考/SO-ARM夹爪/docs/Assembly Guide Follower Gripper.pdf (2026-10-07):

Assembly Guide for Follower Gripper SO-ARM101

This guide provides step-by-step instructions for assembling the parallel gripper. Follow these steps carefully to ensure proper operation.
Required Tools:
- Phillips head screwdriver
- Hex keys M3 and M4
Step 1: Install Linear Bearings in Clamps

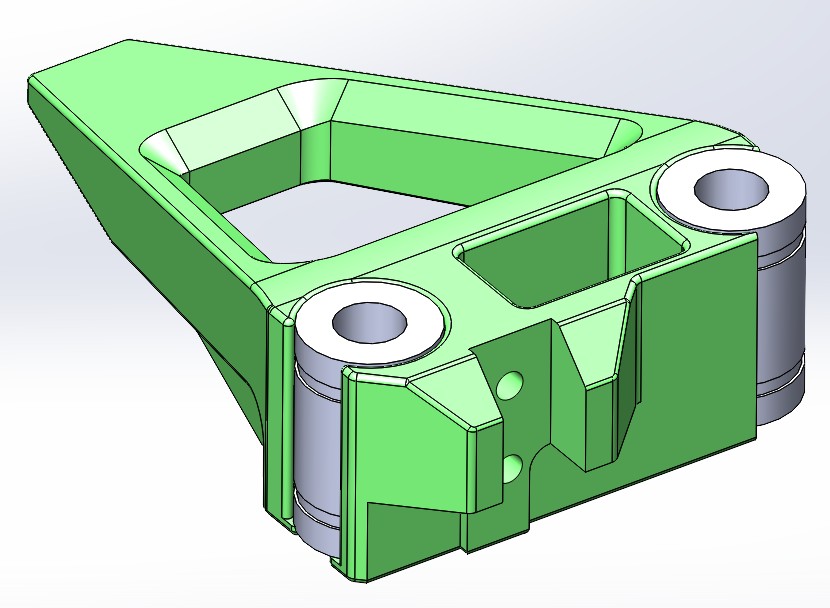
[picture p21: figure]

Components needed:
- 2x Clamps (RB9.01.060.021)
- 4x LM6UU Linear Bearings (12x6x19 mm)
1. Take the first clamp part
2. Carefully press 2x LM6UU bearings into the designated bearing seats, if bearings fit in too easily, wrap some tape around them
3. Ensure bearings are fully seated
4. Repeat for the second clamp
Step 2: Install Gear on Servo Components needed:
- 1x Feetech STS3215 Servo
- 1x Gear for Gripper (RB9.01.060.041)
- 1x Servo disk (from servo kit)
- 1x Servo mounting screw M3x6 (from servo kit)
- 4x Set Screw DIN 913 M3x4

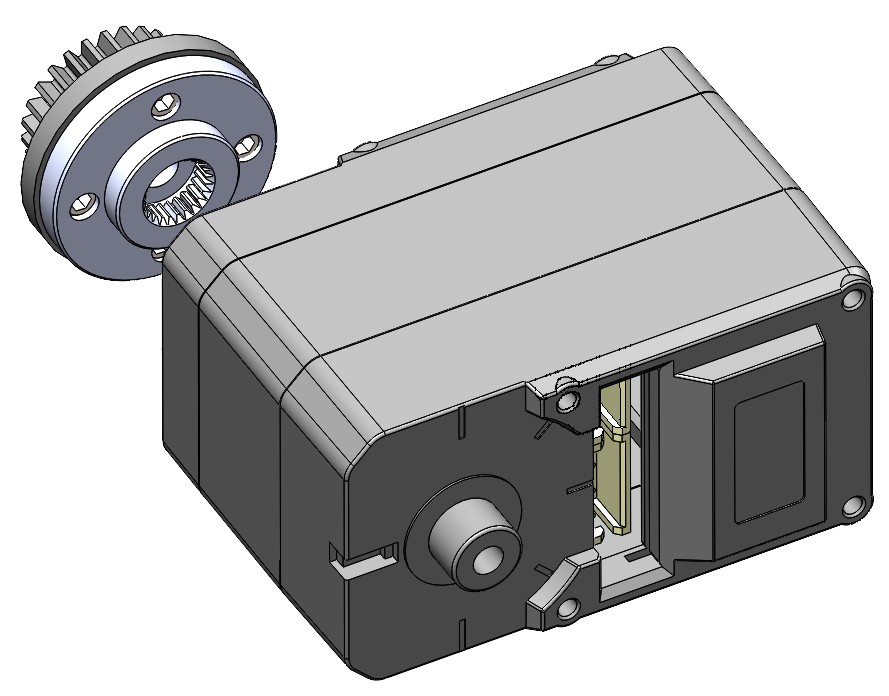
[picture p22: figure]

1. Place Gear for Gripper on Servo disk and fix them together with 4x Set Screws M3x4, pay attention that there is no gap between parts
2. Mount the gear assembly onto the servo output shaft
3. Secure with the screw M3x6 provided in the servo kit
Step 3: Mount Servo on Main Frame

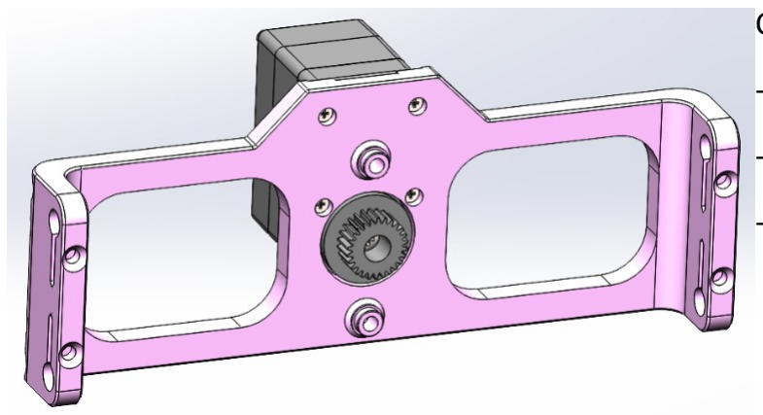
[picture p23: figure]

Components needed:
- 1x Main Frame (RB9.01.060.015)
- 1x Assembled servo with gear
- 4x Self-tapping screws (from servo kit)
1. Position the servo on the main frame and align mounting holes
2. Secure the servo using 4x self-tapping screws from the servo kit
Step 4: Install Bearings on Main Frame

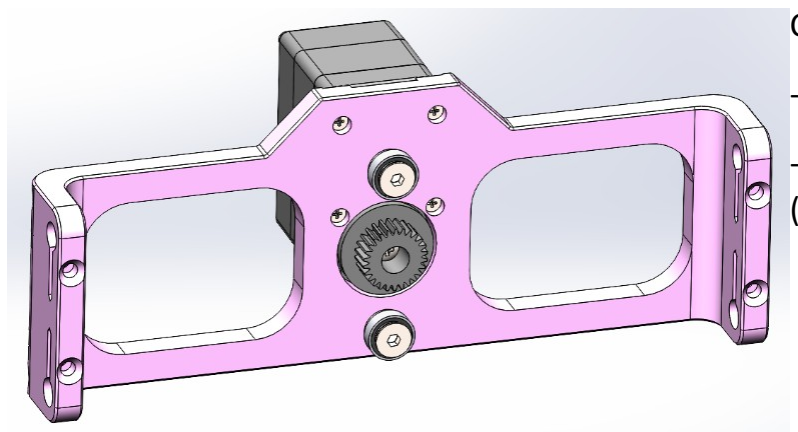
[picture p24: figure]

Components needed:
- 2x MR106ZZ Bearings (10x6x3 mm)
- 2x Self-tapping screws with a large head (from servo kit)
1. Insert the 2x MR106ZZ bearings into their designated positions on the main frame
2. Secure each bearing with self-tapping screw

Step 5: Install Rods and Clamps

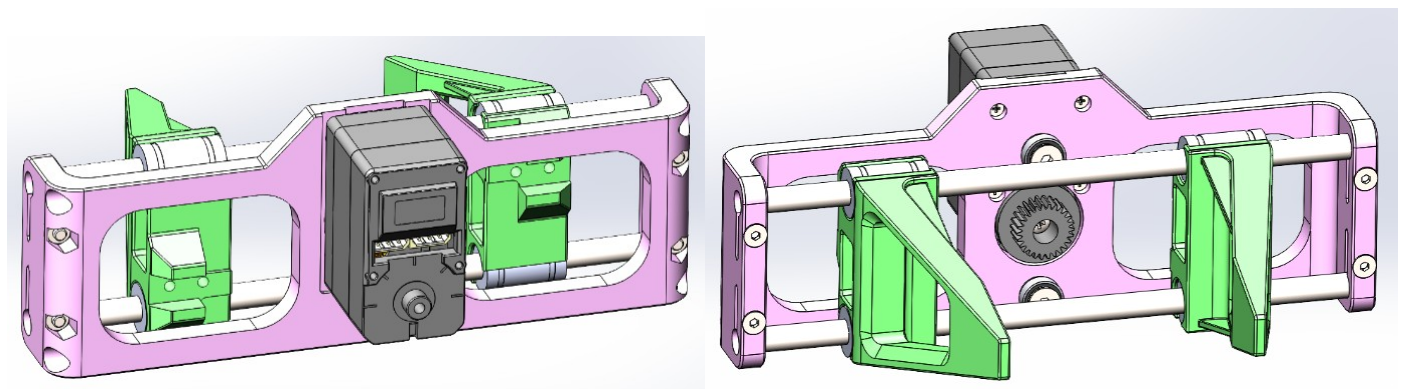
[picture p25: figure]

Components needed:
- 2x Stainless Steel Rods (6mm diameter, 125mm length)
- 2x Assembled clamps (with LM6UU bearings)
- 4x M3x20 DIN 7991 screws
- 4x M3 DIN 934 nuts
1. Insert the 2x steel rods through the one side of main frame
2. Slide the 2x clamps onto the rods
3. Press rods further through the second side of the main frame
4. Secure rods in the main frame using 4x M3x20 screws and 4x M3 nuts
Step 6: Attach Gear Racks

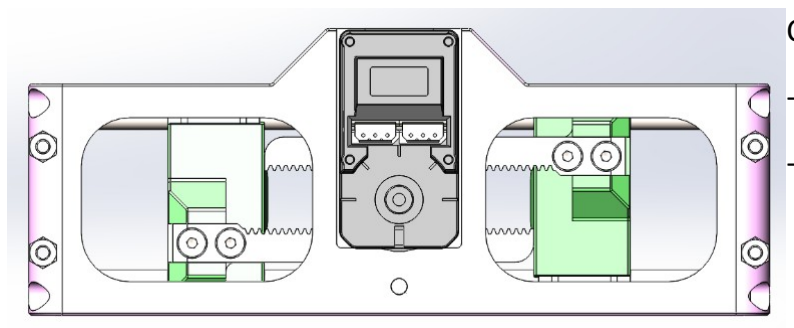
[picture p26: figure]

Components needed:
- 2x Gear Racks (RB9.01.060.030)
- 4x M3x10 DIN 7991 screws
1. Position the gear racks on the back side of each clamp
2. Important: Ensure clamps are symmetrically positioned from the main frame center
3. The gear racks should engage properly with the drive gear
4. Secure each gear rack with 2x M3x10 screws

Step 7: Insert Servo Cable

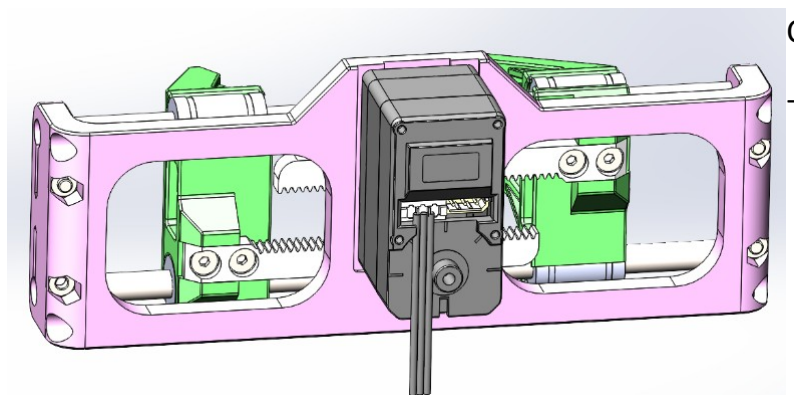
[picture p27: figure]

Components needed:
- Servo cable (from servo kit)
1. Insert cable so it will go straight down
Step 8: Insert Screws for Rigidity

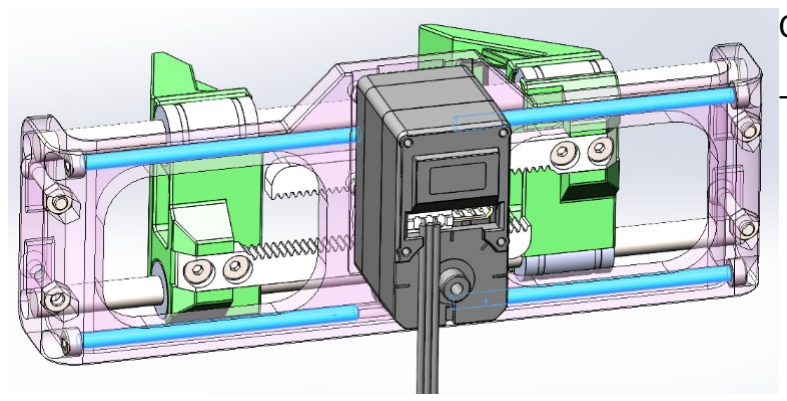
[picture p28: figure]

Components needed:
- 4x M3x50 DIN 912 screws
1. From each side of the Main Frame screw 2x screws M3x50

Congratulations! Gripper is assembled.

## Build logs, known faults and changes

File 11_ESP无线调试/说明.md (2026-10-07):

# 11_ESP无线 —— 无线链路联调记录与操作手册

> 归属：**线路 A**（控制系统接入）。
> 一句话：**"笔记本 → C3 → 无线 → C6 → UART1"这条链路已经实测跑通**（2026-10-01 凌晨）。
> 与 `09_固件\固件设计-协议与引脚.md` 的分工：那份规定 **STM32 侧**的串口协议；本目录负责**链路两端的两块 ESP**。

---

## 0. 当前状态（2026-10-01）

| 项 | 状态 |
|---|---|
| **C3（接电脑）** | ✅ 已刷 **MicroPython v1.29.0**，端口 `COM7`；STA + TCP 客户端 |
| **C6（接装置）** | ✅ 已刷 **MicroPython v1.29.0**，端口 `COM8`；**AP + TCP 服务端 + UART1 透传** |
| **PC → C3 → C6 链路** | ✅ **实测通过**（C3 关联拿 IP → TCP 连上 → 数据写入 C6 的 UART1） |
| **`COM7` = 无线串口线** | ✅ **实测通过**：往 `COM7` 写 `PING-FROM-PC` → C6 的 UART1 收到并原样回传（整行一个包） |
| **C6 的 UART1 通路** | ✅ **硬回环实测通过**（短接 `GPIO4↔GPIO5`：PC 发 21B → 原样 21B 回到 PC；镜像已关，回程只可能走那根线） |
| **C6 ↔ STM32** | ⬜ 未接（等接线；STM32 侧还差 **USART2 驱动**，由线路 A 写） |
| 出厂 demo 固件 | 已整片备份 → `firmware\c6_factory_demo_backup_8MB.bin`（8MB，可随时刷回） |

---

## 1. 架构与角色

| 环节 | 谁 | 说明 |
|---|---|---|
| 电脑 | 笔记本 | 用 **USB 串口**跟 C3 说话；**WiFi 保持联网**（要调云端 AI），所以不占 WiFi |
| 电脑侧 | **ESP32-C3** | `COM7`；**STA** 加入 C6 的热点 + **TCP 客户端**；把 USB 串口与 TCP 互相透传 |
| 空中 | WiFi | SSID **`SORT-C6`**（开放）、**信道 1**、TCP 端口 **3333** |
| 装置侧 | **ESP32-C6** | **AP** + **TCP 服务端** + **UART1 透传** |
| 单片机 | STM32F103RCT6 | 接 C6 的 **UART1**：`GPIO4`(C6 TX) → `PA3`(USART2_RX)、`GPIO5`(C6 RX) ← `PA2`(USART2_TX)、**GND 共地** |

> ⚠️ **为什么用 UART1 而不是 UART0**：`GPIO16/17`(=UART0) 被板载 USB-转串口桥片（CH340K）占着当调试口；
> 拿它接 STM32 会和桥片的 TXD 顶牛（两个 3.3V 输出对驱）。所以 STM32 挂 **UART1**。

---

## 2. 硬件与端口

| 角色 | 板子 | 端口 | 识别特征 |
|---|---|---|---|
| 电脑侧 | **ESP32-C3** | `COM7` | **`303A:1001`** = 乐鑫**原生 USB-Serial-JTAG**（不是 CH340）；MAC `E4:B0:63:22:C4:C4` |
| 装置侧 | **ESP32-C6** | `COM8` | **`1A86:7522` = CH340K**（走板上的 **UART 口**那个 USB-C）；MAC `E8:F6:0A:F6:14:5D` |

⚠️ **CH340K 撞车提醒**：C6 的桥片和 **STM32 板**是**同一颗 CH340K、同一个 VID:PID、都没有序列号** ——
两个一起插时**名字完全一样**，只能靠 COM 号区分（或拔一个看谁消失）。建议**固定插孔**。

**ESP32-C6 板上的两个 USB-C 口**：
- **`UART` 口** ✅ 用它 —— 桥片独立于芯片，**ESP32 复位时 COM 号不变**（我们每次连板子都会复位它，这点很关键）；
- **`OTG` 口**（原生 USB）—— 免驱、也能刷，但**芯片一复位就重新枚举**，脚本容易扑空。缺桥片驱动时才用它顶一下。

---

## 3. 工具链（装在 `hw_bridge\vendor_esp\`，不污染系统 Python）

| 工具 | 版本 | 用途 |
|---|---|---|
| `esptool` | 5.4.0 | 擦除 / 刷写 / **备份** ESP32 固件 |
| `mpremote` | 1.29.0 | 把 PC 上的 `.py` 送到板子上跑、拷文件、看 REPL |

```powershell
$env:PYTHONPATH='C:\Users\22431\Desktop\工创赛智能分拣项目\hw_bridge\vendor_esp'
& 'D:\python\python.exe' -m esptool  --chip esp32c6 --port COM8 flash_id
& 'D:\python\python.exe' -m mpremote connect COM8 ls
```

固件镜像在 `firmware\`（`get_fw.py` 下载，走 Python urllib —— 本机 curl/git 走 schannel 必报 `SEC_E_NO_CREDENTIALS`）：

| 文件 | 大小 |
|---|---|
| `ESP32_GENERIC_C3-20260824-v1.29.0.bin` | 1,754,736 B |
| `ESP32_GENERIC_C6-20260824-v1.29.0.bin` | 1,967,664 B |
| `c6_factory_demo_backup_8MB.bin` | 8,388,608 B（C6 出厂整片备份） |

---

## 4. 刷写流程

```powershell
# ① 先备份（只对 C6 需要，出厂固件留个后路）
& 'D:\python\python.exe' -m esptool --port COM8 --baud 460800 read_flash 0 0x800000 11_ESP无线\firmware\c6_factory_demo_backup_8MB.bin
# ② 擦
& 'D:\python\python.exe' -m esptool --chip esp32c6 --port COM8 erase_flash
# ③ 刷
& 'D:\python\python.exe' -m esptool --chip esp32c6 --port COM8 --baud 460800 write_flash -z 0x0 11_ESP无线\firmware\ESP32_GENERIC_C6-20260824-v1.29.0.bin
```

- ⚠️ **必须先 `erase_flash`**：只 `write_flash` 会留下旧的 LittleFS 分区 → 开机刷屏
  `The filesystem appears to be corrupted …`（实测踩到过，全擦后一次就好）。
- ⚠️ **读/写不要用 921600**：CH340K 在这个速率下会 `Packet content transfer stopped`（实测 8MB 读到 65% 断），**460800 稳定**。
- 刷完不按 BOOT：原生 USB / 桥片都能自动进下载模式；esptool 自己会处理。
- 成功判据：串口出现 `MicroPython v1.29.0 on 2026-08-24; ESP32C3/C6 module with …` + `>>>`。
- **还原出厂固件**：`write_flash -z 0x0 c6_factory_demo_backup_8MB.bin`

---

## 5. 部署与运行

```powershell
# C6（装置侧）：AP + TCP 服务端 + UART1 透传
& 'D:\python\python.exe' -m mpremote connect COM8 cp 11_ESP无线\src\c6_bridge.py :main.py
& 'D:\python\python.exe' -m mpremote connect COM8 reset
# C3（电脑侧）：STA + TCP 客户端 + USB 串口透传（部署后 COM7 就是一根"无线串口线"）
& 'D:\python\python.exe' -m mpremote connect COM7 cp 11_ESP无线\src\c3_bridge.py :main.py
& 'D:\python\python.exe' -m mpremote connect COM7 reset
# 不想让它开机自启：
& 'D:\python\python.exe' -m mpremote connect COM7 rm :main.py
```

**旁观 C6 的调试台**（`main.py` 的 `print` 都走 UART0→COM8）：

```powershell
& 'D:\python\python.exe' hw_bridge\tools\port_probe.py COM8 --baud 115200 --listen 30
```

**自测开关**：`c6_bridge.py` 的 `MIRROR_TO_CLIENT` —— `True` 时把 TCP 收到的数据**回传一份**（还没接 STM32 也能验链路）。
**2026-10-01 已改为 `False`**：接上 UART 硬回环/STM32 后**必须关掉**，否则回程数据会混进"真绕回来了"的证据里。

---

## 6. 验收实测（2026-10-01 凌晨，证据原文）

C3 侧（`src\c3_link_test.py` 的输出）：

```
connect attempt 1 ...
wifi isconnected: True ('192.168.4.2', '255.255.255.0', '192.168.4.1', '192.168.4.1')
tcp: connected to 192.168.4.1:3333
TX: b'HELLO-FROM-C3\n'      RX: b'<mirror>HELLO-FROM-C3\n\x00'
TX: b'SECOND-LINE\n'        RX: b'<mirror>SECOND-LINE\n'
```

C6 侧（COM8 调试台）：

```
[C6] no password -> OPEN ap
[C6] txpower=2.0 dBm
[C6] protocol=11b/g/n(7)
[C6] AP up  ssid=SORT-C6 ch=1 ip=192.168.4.1
[C6] UART1 up tx=GPIO4 rx=GPIO5 baud=115200
[C6] TCP listening on 192.168.4.1:3333
[C6] stations=[(b'\xe4\xb0c"\xc4\xc4', '192.168.4.2')]      ← C3 关联 + 拿到 DHCP 地址
[C6] client connected from ('192.168.4.2', 58996)
[C6] TCP->UART 14 B (total 14): b'HELLO-FROM-C3\n'          ← 数据真的写进 UART1
[C6] TCP->UART 12 B (total 26): b'SECOND-LINE\n'
```

⇒ **PC → C3 → 无线 → C6 → UART1（STM32 那条口）** 与 **回程** 双向都通。

### 6.1 最终形态：`COM7` 就是一根"无线串口线"

C3 部署 `c3_bridge.py` 为 `main.py` 之后，**电脑侧把它当普通串口用**（`hw_bridge` 那套工具原样可用）：

```
& 'D:\python\python.exe' hw_bridge\tools\port_probe.py COM7 --send "PING-FROM-PC" --crlf --send-after 14 --listen 8
  → TX 14 B: PING-FROM-PC\r\n
  → RX 22 B: <mirror>PING-FROM-PC\r\n        ← `<mirror>` 是自测开关加的，接 STM32 后关掉
```

同一次测试里还意外验证了**断线自动重连**：监听端复位 C6 后，C3 侧打印
`tcp connect failed: OSError(113,) (retry in 2s)`，两秒后自己重连并继续把数据送达。

C6 侧同一时刻的日志（对比第 7 节坑#6：修批量读之前这里是 `1 B / 3 B / 6 B / 4 B` 四段）：

```
[C6] client connected from ('192.168.4.2', 49631)
[C6] TCP->UART 14 B (total 14): b'PING-FROM-PC\r\n'      ← 整行一次写入 UART1
```

### 6.2 UART1 硬回环闭环（2026-10-01，`GPIO4` 与 `GPIO5` 用杜邦线短接）

把 `MIRROR_TO_CLIENT` 关掉之后，**回程数据只可能来自那根短接线**，于是这条测试能把"UART1 通不通"焊死：

PC 侧（`COM7`）：

```
TX 21 B: LOOPBACK-TEST-12345\r\n
RX 21 B: LOOPBACK-TEST-12345\r\n        ← 一字不差，且**没有** <mirror> 前缀
```

C6 侧：

```
[C6] MIRROR_TO_CLIENT=False
[C6] TCP->UART 21 B (total 21): b'LOOPBACK-TEST-12345\r\n'   ← TCP 进 → 写进 UART1(GPIO4)
[C6] UART->TCP 16 B (total 16): b'LOOPBACK-TEST-12'          ← 从 UART1(GPIO5) 收回
[C6] UART->TCP  5 B (total 21): b'345\r\n'                   ← 合计 21 B，与发出完全一致
```

⇒ **"笔记本 → C3 → 无线 → C6 → UART1 出 → 线 → UART1 回 → C6 → 无线 → C3 → 笔记本"整圈打通**。
把短接线换成 STM32 的 `PA3/PA2`，这条链就直接服务分拣主控了。

---

## 7. ⚠️ 踩坑清单（按踩到的顺序，都很隐蔽）

| # | 现象 | 真因 | 处理 |
|---|---|---|---|
| 1 | 板子一开机刷屏 `partition 0 invalid magic number` / `filesystem corrupted` | 只 `write_flash` 没 `erase_flash`，旧文件系统残留 | **先擦后刷** |
| 2 | `main.py` 一跑就 `AttributeError: 'TextIOWrapper' object has no attribute 'flush'` | 这个构建的 `sys.stdout` **没有 `flush()`** | flush 一律包 `try/except` |
| 3 | **C3 扫得到热点（-40dBm）却连不上**：status 一路 `CONNECTING→IDLE`、`isconnected()` 恒 False | **`ap.ifconfig((静态IP…))` 在 ESP32-C6 上抛 `Wifi Unknown Error 0x5001`，并把软 AP 的 DHCP 服务搞停** → 客户端**能关联但永远拿不到 IP** | **别调 `ap.ifconfig`**；AP 默认 `192.168.4.1` + 自带 DHCP。要静态 IP 在**客户端**设 |
| 4 | 偶发 `OSError: Wifi Internal State Error` | STA 还记着**已经消失的旧热点** | `active(False)` → 停 0.6s → `active(True)` 彻底复位射频 |
| 5 | 两块板贴在一起时信号 **-6 dBm**（过热） | 20dBm 发射 + 距离几厘米 = 接收端可能饱和 | `ap.config(txpower=2.0)`，两端都压功率；装置装好后可调回 8~20 |
| 6 | 回传里 `<mirror>` **每字节出现一次** | C3 侧 `read(1)` 就 `send` → **一个字节一个 TCP 包** | 一次 poll 到就把**当前可读的全部取走**再发（实测：整行 14B 合成 1 包） |
| 7 | 批量读改成 `if poller.poll(0):` 当判据后，**整条桥卡死、一个字节都发不出** | `poll(0)` 把 **socket 的事件**也算进来了 → 没有更多 USB 字节时继续 `read(1)` **阻塞** | 判据必须是"**只有 stdin 可读**"：`for obj,ev in poller.poll(0): if obj is sys.stdin and ev & POLLIN`（已封装成 `stdin_ready()`） |

**排查心法（本次最有价值的一招）**：
在 AP 那侧打印 **`ap.status("stations")`** —— 它直接告诉你"客户端到底有没有关联上"。
本次就是靠 `stations=[(b'\xe4\xb0c"\xc4\xc4', '192.168.4.2')]` 一句话把范围从"C3 连不上"缩到"**C3 连上了、是拿不到 IP**"。
**"关联"与"拿到 IP"是两件事，中间隔着 DHCP。**

---

## 8. 网络参数速查

| 项 | 值 | 备注 |
|---|---|---|
| SSID | `SORT-C6` | 开放热点（联调期先不加密：WPA2 握手是额外一个失败环节；DHCP 修好后可再评估） |
| 信道 | `1` | 现场扫到 34~39 个 AP，`ch6` 最挤（12 个）；装好后可再挑 |
| C6(AP) IP | `192.168.4.1` | 默认值，别去改 |
| C3(STA) IP | `192.168.4.2` | DHCP 自动给；拿不到时脚本会强制静态 |
| TCP 端口 | `3333` | |
| 发射功率 | `2.0 dBm`（两端） | 抗饱和；距离拉开后可调回 |
| AP 协议 | `11b/g/n(7)` | C6 是 11ax 芯片，显式限到 11n 排除兼容问题 |

---

## 9. 下一步

1. **STM32 侧（线路 A 的固件活）**：加 **USART2 驱动**（照 USART3 屏那套抄）→ 与 C6 的 UART1 对接（115200 8N1）→ 之后再加批量计划下发 `PLAN` 与状态机"计划就绪"前置。
2. **接线**（3 根线即可）：`C6 GPIO4(TX) → STM32 PA3(RX)`、`C6 GPIO5(RX) ← STM32 PA2(TX)`、**GND 共地**。
   ~~没有 STM32 时想先验 UART 通路：短接 GPIO4/GPIO5~~ → ✅ **2026-10-01 已验完**（见 §6.2），**记得把短接线拔掉**，否则它会一直把 STM32 的 RX 短路掉。
3. 部署 `c3_bridge.py` 为 C3 的 `main.py` → **`COM7` 变成一根"无线串口线"**，现有 `hw_bridge` 工具链可原样复用。~~✅ 已部署~~
4. ~~`MIRROR_TO_CLIENT` 改回 `False`~~ → ✅ **已改**（§6.2 就是关掉镜像后测的）。
5. 决定要不要重新启用 WPA2（DHCP 修好后重测一次即可）。
6. ⚠️ **现场形态提醒**：两块板的 `txpower` 现在是 `2.0 dBm`（因为贴在一起）。装进装置后如果两块板离得远
   （笔记本在桌上、装置在台面），若出现掉线就把 `TXPOWER_DBM` 调回 **8~20**；反之越近越要压低。

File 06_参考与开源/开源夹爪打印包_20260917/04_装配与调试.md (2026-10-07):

# 装配与调试（9 步 + 我们自己的接口）

> 队内资料。原文：`参考\SO-ARM夹爪\docs\assembly-guide.md` + `Assembly Guide Follower Gripper.pdf`（含图）。
> 下面按我们的场景重写：**省掉 SO-ARM 机械臂那一步，换成"接到龙门 Z 轴"**。

---

## 1 需要的工具

| 工具 | 规格 | 用途 |
|---|---|---|
| 十字螺丝刀 | PH1 | 舵机自攻螺钉 |
| 内六角 | H1.5（M2）、H2.0（M3）、H2.5（M4） | 全部内六角螺钉 |
| 尖嘴钳 / 小台钳 | — | 压 Ø6 杆、压轴承 |
| 上位机 | Windows + 总线舵机调试工具 | 设 `Max Torque Limit`（路线 A 必做） |

---

## 2 装配 9 步

| 步 | 做什么 | 用的件 | 关键点 |
|:--:|---|---|---|
| 1 | **齿轮装舵盘** | 齿轮 + 舵机自带圆盘 + 4×M3×4 紧定 + 1×M3×6 | 从舵盘一侧往齿轮拧，**拧紧后盘与齿轮之间不能有缝**；再整体压到舵机输出轴上，用 M3×6 锁住 |
| 2 | **舵机限矩（别跳）** | 总线转接板 + 上位机 | 1 Mbps 连上 → 勾选使能扭矩 → **`Max Torque Limit` 设 500** → Save。**不设的话第一次夹到硬物会把机构顶坏** |
| 3 | **夹爪 + 齿条 + 销** | 2×夹爪 + 2×齿条 + **2×销（补打件）** | 齿条从**侧面**插进夹爪；销从**背面**插到底，卡住齿条（不装销，齿条会窜） |
| 4 | **穿导杆** | 2×Ø6×125 杆 | 两根杆同时穿过两片夹爪的星形孔；杆长了锯到 125 |
| 5 | **主框装轴承** | 2×MF106ZZ + 2×M4×8 | 轴承**法兰面朝上**压入，各用 1 颗 M4×8 压住 |
| 6 | **合装** | 步 4 的组件 + 主框 | 把两根杆"咔"进主框；把两爪推到左右极限 |
| 7 | **舵机装主框** | 3×自攻（舵机自带） | 先对中位再上螺钉，避免装上后爪不对中 |
| 8 | **装连接耳 → 换我们的 Z 轴转接板** | `060.080 安装支架`（或 `060.074 相机支架`） | 原设计是拧到机械臂腕部舵盘上；**我们改成：把 060.080 当连接耳，自画一块转接板接到 Z 轴滑块**（见 §3） |
| 9 | **（可选）装相机** | 相机 + `060.090 垫片` + 4×M2×8 + 4×M2 螺母 | 我们是"相机在上方看料盘"，**夹爪上不需要装相机**，这步可以跳过 |

---

## 3 我们额外要做的：Z 轴转接板

| 项 | 内容 |
|---|---|
| 现有接口 | 夹爪侧的连接耳 `RB9.01.060.080 安装支架`（17×48×37），用 4×M3×6 与主体相连；它的另一面是给 SO-ARM 腕部的 |
| 我们要的 | Z 轴滑块（我方 4040/MGN12 滑块）→ 该连接耳 |
| 怎么做 | 在 Fusion 打开 `参考\SO-ARM夹爪\models\RB9.01.062.000 Gripper.STEP`，量出连接耳那 4 个 M3 孔的位置与间距，画一块 3~4mm 铝板/PLA 板（两边孔位各一组），M3 螺钉对锁；**铝板优于打印件**（Z 轴是悬臂，抗弯） |
| 校核 | 装上后手压夹爪尖端 5N，测变形 <1mm；不行就加厚到 5mm |

---

## 4 通电自检（5 分钟）

| 检查 | 方法 | 合格判据 |
|---|---|---|
| 中位 | 给中位指令 | 两爪对称、开口约 42mm（行程一半） |
| 同步 | 慢速全开→全闭 3 次 | 两爪**同步**、无异响、无卡顿 |
| 回差 | 夹住 20mm 方块，手左右轻推 | 位移 ≤ 0.3mm |
| 行程 | 全开 → 量开口 | ≈ 84mm |
| 限矩 | 空夹到极限并保持 2s | 舵机不尖叫、机构不响 |
| 温升 | 连续动作 20 次 | 舵机外壳温热不烫手 |

---

## 5 常见故障 → 处理

| 现象 | 原因 | 处理 |
|---|---|---|
| 开合卡滞、一顿一顿 | 齿条/齿轮层高太粗、有毛刺；轴承螺钉压太紧 | 齿条齿轮重打 `0.12mm / 100%`（关熨烫）；M4 轴承螺钉松 1/4 圈 |
| 两爪不同步、歪 | 齿轮与舵盘没贴合；齿条某一侧销没插到底 | 拆开重装步 1、步 3 |
| Ø6 杆装不进 / 太晃 | 夹爪星形孔档位不对 | 打 `Gripper test plate star holes 6.0-6.3.STL` 挑档，再打对应 `D6.x` 夹爪 |
| 夹住后货物打滑 | 爪面光滑（PLA μ≈0.3） | **贴爪垫**（`爪垫_锯齿_70x14x2.stl`，TPU）或 1.5mm 3M 背胶硅胶垫 |
| 舵机发热/异味 | 限矩没设或设太大；堵转 | 确认 `Max Torque Limit=500`；检查机构是否卡死 |
| 齿轮打齿 | 打印填充不足 / 撞击 | 齿轮齿条改 100% 填充重打；加软启动（闭合前 200ms 降速） |
| 投放时货物弹跳出台 | 落料高度太高 | 盒口上方 20~30mm 松开；盒底垫 2mm 硅胶/泡棉 |

---

## 6 装到整机上以后（与运动程序的约定）

| 约定 | 值 | 原因 |
|---|---|---|
| 取料高度 | 爪垫中心对货物**中上部** | 重心之上，抗摆动 |
| 闭合后保持 | 80~120 ms 再抬升 | 消除齿条空程、让爪垫完全贴合 |
| 抬升速度 | ≤ 150 mm/s | 抑制货物摆动 |
| 横移速度 | ≤ 300 mm/s，加减速 ≤ 1000 mm/s² | 惯性力 ≈ 0.1N，远小于摩擦力（见 `05_抓取稳定性.md`） |
| 投放方式 | **盒口上方 20~30mm 松开** | 这套夹爪 128×109 进不了 82mm 盒口 |
| 落料确认 | 入盒对射传感器 + 松开后停 100ms | 本次件无夹持反馈；总线舵机可读负载做辅助判据 |

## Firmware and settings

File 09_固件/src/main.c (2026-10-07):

/* M1 固件 —— 线协议解析 + 安全状态机
 *
 * M1 的目标：**把"通信层 + 安全门"钉死，但一个执行器都不碰**。
 * 因此这里所有运动/执行器命令都只做"该不该被允许"的判断，不做实际动作。
 * 判据（验收用）：
 *   PING        → OK pong
 *   乱码         → ERR 1 unknown（不装死）
 *   MOVE        → ERR 11 not homed（安全门真的生效）
 *   ESTOP/CLEAR → 状态真的变化
 *
 * 协议全文见 09_固件/固件设计-协议与引脚.md §3。
 */

#include "board.h"

#include "boot_marker.h"
#include "stm32f10x.h"

#define FW_VERSION "0.8.1"   /* 0.8.1：Z 端点按实测收紧（10°~170° ⇒ 630/2370µs，原 600/2400 各超 11µs） */
#define PROTO_VERSION "1"

#define LINE_MAX 160u /* 行长上限；超了回 ERR 10，避免缓冲区被灌爆。
                       * 2026-09-22 由 64 提到 160：串口屏指令（`LCD <内容>`）带中文
                       * 文本时 64 字节不够用（UTF-8 一个汉字 3 字节）。 */

/* --------------------------------------------------------------------------
 * 波特率测速模式（M1 临时诊断，测准后改 0）
 *
 * 背景：2026-09-21 实测——固件发出去的字节在 PC 侧全是乱码，而 bootloader 的字节
 * 完全正常。bootloader 不受影响是因为它**从 0x7F 自动测波特率**；固件则是按
 * "HSI = 8MHz"硬算 BRR。所以要么 HSI 不是 8MHz，要么 BRR 算错了。
 * 没有示波器、晶振丝印也看不清，于是用最朴素的办法测：
 *
 *   连发 500 行已知长度的文本 → 桥按行记录到达时间 → 首尾时间差 = 传输耗时
 *   → 真实波特率 = 总字节数 × 11bit ÷ 耗时   （8E1 = 1起始+8数据+1校验+1停止）
 *   → 真实主频 = 波特率 × BRR
 *
 * 500 行 × 18 字节 = 9000 字节，耗时约 1 秒 —— 用毫秒级时间戳测，误差 <0.2%。
 * ------------------------------------------------------------------------ */
/* 诊断模式：1 = 只做"测波特率"（`03_...` 未完，见日志），0 = 正常的 M1 固件。
 * 默认 0，让 build/m1.bin 就是 M1 本身；需要再排查时改成 1 即可。 */
#define BAUD_SELFTEST 0

/* 心跳诊断开关：1 = 启动后不进命令循环，改成每秒重复输出一行已知字符串。
 * 用来排查"串口乱码"时**摆脱对复位的依赖**（详见 main() 里的说明）。 */
#define HEARTBEAT 0

/* --------------------------------------------------------------------------
 * 中断开关（2026-09-22 线路 A 诊断后定案）：ALLOW_IRQ = 1 表示**不关中断**
 *
 * 背景：交接文档 §6 第 6 项记着"`systick_init()` 一开 TICKINT，`uart_puts` 就卡在
 * 等 TXE"，M1 靠下面的 `__disable_irq()` 绕开。但 **M3 的步进引擎必须用定时器
 * 中断**（20kHz 脉冲），绕不过去 → 现在把现象复现出来、定位它。
 *
 * ⚠️ 当前 `UART_RX_IRQ = 0`（见 board.c）→ USART1 的 NVIC 根本没开，
 *    所以打开中断后**唯一**会打断 CPU 的只有 SysTick。于是本实验的判读是：
 *      banner 四行完整 + `PING`→`OK pong`  ⇒ SysTick/TICKINT 安全，坑不在这里
 *      banner 完整     + PING 无回复        ⇒ 主循环能跑，不是中断风暴 → 另查
 *      banner 缺行／没有 + 无回复            ⇒ **中断风暴复现** → 读 RAM 脚印定位
 *
 * ✅ **结论（2026-09-22 实验 1 + 实验 2 实测）**：SysTick（TICKINT）与 USART1
 *    RX 中断路径**都正常**。
 *    当年的"坑"真凶是**向量表下标错位**（见 startup.c 第 89-93 行）：USART1 的向量
 *    被放到了 IRQn 21，真正的 IRQn 37 位置仍是 0 → **开中断 + RX 线上一个噪声起始位
 *    就跳到地址 0 跑飞**；卡死恰好落在"开中断后的第一次 uart_puts"，因此被误记成
 *    "SysTick 一开 TICKINT 就卡 TXE"。该错误已修 → 中断可放心用。
 *    → **保持 1**（M3 的定时器中断就靠它）；置 0 只用于"怀疑中断时快速排除"。
 * ------------------------------------------------------------------------ */
#define ALLOW_IRQ 1

/* --------------------------------------------------------------------------
 * 状态机（《设计》§4）。M1 可达的状态：
 *   INIT → IDLE_UNHOMED →(ESTOP)→ ESTOP →(CLEAR)→ IDLE_UNHOMED
 * HOMING/READY/MOVING 要等 M3 有了电机才有意义。
 * ------------------------------------------------------------------------ */
typedef enum {
    ST_INIT = 0,
    ST_IDLE_UNHOMED,
    ST_HOMING,
    ST_READY,
    ST_MOVING,
    ST_ESTOP,
    ST_FAULT,
} state_t;

static state_t s_state = ST_INIT;
static uint8_t s_homed = 0;         /* 位0=X 位1=Y；M1 恒为 0 */

/* ==========================================================================
 * M5 —— 「计划」收发：视觉板 K210（或赛前上位机）把**整批货的分拣计划**一次性交给 STM32
 *
 * 为什么要这么设计（对应规则红线"**运行期零外部通讯**"）：
 *   计划必须在**一键启动之前**整包给完；启动后 STM32 只执行，不再接受任何外部指令。
 *   所以协议做成"**声明总数 → 逐条上报 → 整包校验**"，中间任何一条不合法就整包作废。
 *
 * 报文（都带 `@` 前缀从视觉口进来，见 feed() 的过滤）：
 *   @PLAN <N>                      声明本次 N 条（1..24）
 *   @P <i> <x_mm> <y_mm> <box> <img> <name>  第 i 条（i 从 1 开始，必须顺序）
 *   @PLAN END                      收尾：条数对得上、且每条都合法 → 整包生效
 *   @PLAN?                         查询：ready/have/expect
 *   @PCLEAR                        清空（重来）
 *   @PPLAN                         打一份摘要（前若干条）
 *
 * 字段含义：
 *   x_mm / y_mm : 托盘坐标，**毫米**（有符号）—— 视觉侧算好，STM32 不懂像素
 *   box         : 1..6 号储物盒
 *   img         : 串口屏里那张货物图片的 ID（2..21）
 *   name        : 货物名称（最长 15 字符，给屏显示用；带中文时由屏侧按 GBK 处理）
 *
 * ⚠️ 校验口径：**整包要么全收、要么全废**（`PLAN END` 才生效）。
 *    单条里任何字段越界 → 那一条 `ERR`，并且**整包标记为坏**，不再接受 END。
 * ========================================================================== */
#define PLAN_MAX 24
#define PLAN_NAME_MAX 16

typedef struct {
    int16_t x_mm;
    int16_t y_mm;
    uint8_t box;      /* 1..6 */
    uint8_t img;      /* 屏内图片 ID */
    char    name[PLAN_NAME_MAX];
} plan_item_t;

static plan_item_t s_plan[PLAN_MAX];
static uint8_t s_plan_have;    /* 已收到的条数 */
static uint8_t s_plan_expect;  /* 声明要收几条 */
static uint8_t s_plan_ready;   /* 1 = 整包校验通过、可用于执行 */
static uint8_t s_plan_bad;     /* 1 = 本包已出错（END 会被拒） */

static uint32_t s_pos_x = 0;        /* 单位：步（M1 只是占位，恒为 0） */
static uint32_t s_pos_y = 0;
static uint16_t s_servo_z = 0;      /* 单位：µs 脉宽；M1 恒为 0 */
static uint16_t s_servo_grip = 0;
static uint8_t s_box_mask = 0;      /* 位0..5 = 入盒 1..6；M1 恒为 0（M2 接对射） */
static uint8_t s_z_inv = 0;         /* Z 轴百分比方向反转：1 = 0%↔100% 对调 */

/* ---- M2：入盒检测消抖参数（2026-09-22 按实测数据改，非阻塞采样）------------
 * 起因：原实现是"状态一变就隔 1ms 再采一次"，实测在 **1ms 内连跳三次**
 *   （840.349s box=000001 → 840.350s box=000000 → 840.350s box=000001）。
 * 这种抖动到 M4 会让 AI 把"一次移开"数成好几件货，而规则里"未全入盒不计数"
 * 代价很高，必须现在拍死。口径取《设计》§6：每 5ms 采一次、连续 4 次一致
 * 才认账（= 20ms）。
 * ⚠️ 刻意**不用阻塞忙等**：STM32 的 UART 只有 2 字节缓冲，阻塞 20ms 会丢掉
 *    上百个字节、把命令吃掉。这里用已在跑的 **TIM3（1MHz → 1 tick = 1µs）
 *    当时间基准**，采样间隔到了才看一眼，其余时间照常收串口；
 *    也刻意不碰 SysTick 中断（见交接文档 §6 第 6 项那个坑）。
 * ⚠️ TIM3 的 CNT 按 ARR 回绕（0~19999，周期 20ms），所以比较用
 *    "无符号减法"（(uint16_t)(now - last)），回绕时依然正确。
 * ------------------------------------------------------------------------ */
#define BOX_SAMPLE_MS 5u   /* 采样间隔（ms） */
#define BOX_STABLE_N  4u   /* 连续一致次数 → 5ms × 4 = 20ms */

static uint8_t  s_box_cand = 0;    /* 候选状态（还没被认账的读数） */
static uint8_t  s_box_cnt = 0;     /* 候选状态已连续一致的次数 */
static uint16_t s_box_last_us = 0; /* 上次采样时刻（TIM3->CNT 的 µs 计数） */

/* 百分比 → 脉宽。**只作用于 Z 轴的百分比命令**（ZPCT/ZUP/ZDOWN）；
 * ZSET 是"直接给脉宽"，永远不经过这里，否则标定时会被自己绕晕。
 * 注意映射到的是**工作行程** SERVO_Z_LO/HI（600~2400µs，两端留了余量），
 * 不是舵机的能力极限 500~2500µs —— 详见 board.h 里那段说明。 */
static uint16_t z_pct_to_us(uint32_t pct)
{
    uint16_t us = (uint16_t)(SERVO_Z_LO_US + (SERVO_Z_HI_US - SERVO_Z_LO_US) * pct / 100u);
    if (s_z_inv) {
        us = (uint16_t)(SERVO_Z_LO_US + SERVO_Z_HI_US - us);
    }
    return us;
}

/* --------------------------------------------------------------------------
 * 无 printf 的字符串拼装（M1 刻意不用 stdio：一旦引了 printf，标准库会把
 * 半主机（semihosting）拖进来，没有调试器时程序会卡死在 BKPT —— 这类问题
 * 极难查。报文都短，手拼最省心。）
 * ------------------------------------------------------------------------ */
static char *put_str(char *out, const char *text)
{
    while (*text != '\0') {
        *out++ = *text++;
    }
    return out;
}

static char *put_u32(char *out, uint32_t value)
{
    char tmp[11];
    int n = 0;
    if (value == 0) {
        *out++ = '0';
        return out;
    }
    while (value != 0 && n < 10) {
        tmp[n++] = (char)('0' + (value % 10u));
        value /= 10u;
    }
    while (n > 0) {
        *out++ = tmp[--n];
    }
    return out;
}

/* 带符号整数（M3b 的 POS 要用：位置可能是负的） */
static char *put_i32(char *out, int32_t value)
{
    if (value < 0) {
        *out++ = '-';
        return put_u32(out, (uint32_t)(-value));
    }
    return put_u32(out, (uint32_t)value);
}

static void reply(const char *text)
{
    uart_puts(text);
    uart_puts("\r\n");
}

static void send_ok(const char *payload)
{
    uart_puts("OK");
    if (payload != 0 && *payload != '\0') {
        uart_puts(" ");
        uart_puts(payload);
    }
    uart_puts("\r\n");
}

static void send_err(uint32_t code, const char *msg)
{
    char buf[80];
    char *p = buf;
    p = put_str(p, "ERR ");
    p = put_u32(p, code);
    p = put_str(p, " ");
    p = put_str(p, msg);
    *p = '\0';
    reply(buf);
}

static const char *state_name(state_t state)
{
    switch (state) {
    case ST_INIT:         return "INIT";
    case ST_IDLE_UNHOMED: return "IDLE_UNHOMED";
    case ST_HOMING:       return "HOMING";
    case ST_READY:        return "READY";
    case ST_MOVING:       return "MOVING";
    case ST_ESTOP:        return "ESTOP";
    case ST_FAULT:        return "FAULT";
    default:              return "?";
    }
}

static int streq(const char *a, const char *b)
{
    while (*a != '\0' && *a == *b) {
        a++;
        b++;
    }
    return *a == *b;
}

/* --------------------------------------------------------------------------
 * 安全门：所有运动/执行器命令都要先过这里。
 * 顺序很重要 —— 先判急停，再判回零：急停态下的报错必须是 ERR 14（更严重），
 * 否则操作者会以为是"忘了回零"，去回零，而设备其实还处在急停里。
 * ------------------------------------------------------------------------ */
static int motion_allowed(void)
{
    if (s_state == ST_ESTOP || s_state == ST_FAULT) {
        send_err(14, "estopped - send CLEAR first");
        return 0;
    }
    if (!s_homed) {
        send_err(11, "not homed - send ZERO x|y|all (or HOMED 1) first");
        return 0;
    }
    return 1;
}

/* --------------------------------------------------------------------------
 * 命令处理
 * ------------------------------------------------------------------------ */
#define MAX_TOKENS 8

static int parse_u32(const char *s, uint32_t *out)
{
    uint32_t v = 0;
    int digits = 0;

    while (*s >= '0' && *s <= '9') {
        v = v * 10u + (uint32_t)(*s - '0');
        s++;
        digits++;
    }
    if (digits == 0 || *s != '\0') {
        return 0; /* 空串或含非数字字符都算非法 */
    }
    *out = v;
    return 1;
}

/* M3 用：带符号整数（`STEP x -500` 这种）。允许前导 +/-，其余规则同 parse_u32。 */
static int parse_i32(const char *s, int32_t *out)
{
    uint32_t v = 0;
    int neg = 0;

    if (*s == '-') {
        neg = 1;
        s++;
    } else if (*s == '+') {
        s++;
    }
    if (!parse_u32(s, &v)) {
        return 0;
    }
    *out = neg ? -(int32_t)v : (int32_t)v;
    return 1;
}

/* 屏指令等"原样透传"命令的原始参数区。
 * ⚠️ 为什么需要它：下面的分词会把空格改写成 '\0'，而 `LCD page0.t0.txt="a b"` 这类
 *    屏指令**内部空格是有意义的**，所以必须在分词之前先抄一份出来。 */
static char s_arg_raw[LINE_MAX];

/* 诊断开关：USART2 收到什么就立刻原样吐回去（命令 `U2ECHO 1`）。
 * 用途：**不依赖上层解析**，直接验证"无线链路 ↔ USART2"这条电气通路通不通。
 * ⚠️ 开着时别接真实上位机（会把数据搅乱），验完记得 `U2ECHO 0`。 */
static int s_u2_echo = 0;

static int hex_val(char c)
{
    if (c >= '0' && c <= '9') { return c - '0'; }
    if (c >= 'a' && c <= 'f') { return c - 'a' + 10; }
    if (c >= 'A' && c <= 'F') { return c - 'A' + 10; }
    return -1;
}
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
int main(void)
{
    /* ---- 全局关中断 ----
     * Cortex-M3 复位后 PRIMASK=0，中断本来就是全局开启的；而 board_init 末尾
     * ⚠️ **2026-09-22 订正（实验 1/2 实测）**：原先这里记的"一开 TICKINT 就卡
     * uart_puts"**是误判**。真相是**向量表下标错位**（见 startup.c 第 89-93 行）：
     * USART1 的向量被放到 IRQn 21、真正的 IRQn 37 是 0 → "开中断 + RX 线上一个噪声
     * 起始位"就跳到地址 0 跑飞；卡死恰好落在开中断后的第一次 uart_puts 上。
     * 该错误已修 → SysTick(TICKINT) 与 USART1 RX 中断**都实测正常**，
     * 故默认 ALLOW_IRQ=1（不关中断），M3 的定时器中断直接可用。 */
#if !ALLOW_IRQ
    __disable_irq();
#endif

    BOOT_MARKER = MARK_MAIN_ENTERED;

#if BAUD_SELFTEST
    /* ------------------------------------------------------------------
     * 波特率自校准（M1 诊断）
     *
     * 关键洞察：**BRR 的物理含义就是"一个 bit 占多少个 HCLK 周期"**
     *           —— 因为 BRR = USARTDIV×16 = f_cpu/(16×baud)×16 = f_cpu/baud。
     * 所以只要测出 PC 发来的**连续字节之间的 HCLK 周期数**，再除以每字节的位数
     * （8E1 = 11 位），结果**直接就是该写的 BRR** —— 完全不需要知道主频多少。
     *
     * 这正是出厂 ROM bootloader 自动测波特率的同一招，也是它为什么能在
     * "晶振频率不明"的板子上照常工作的原因。
     *
     * 测完把 BRR 写进去，紧接着打印测量结果 —— 因为此时波特率已经配对，
     * 这行输出在 PC 上一定是可读的（如果还读不懂，那就不是波特率的问题）。
     * ------------------------------------------------------------------ */
    board_early_uart(); /* 先用试探值 BRR=69 把接收跑起来 */

    /* ------------------------------------------------------------------
     * 波特率自校准（用"总时长"，不用"帧数"）
     *
     * 原理：PC 连发 N 个字节，占用 N×11 个位时间（8E1 = 11 位/字节）。
     *       固件用 SysTick 量出整束的起止时长（HCLK 周期），则
     *              BRR = f/baud = 总周期数 ÷ (N × 11)
     *       —— 又因为 BRR 的物理含义就是"一个 bit 占多少 HCLK 周期"，
     *          这个式子**根本不需要知道主频是多少**。
     *
     * ⚠️ 关键修正（上次失败的真正原因）：**除数必须用"PC 实际发出去的字节数"，
     *    而不是"固件自己数到的帧数"**。波特率失配时接收端会把 N 个字节错帧成
     *    更多帧（上次 64 字节被数成 74 帧），拿它当除数会让算出的 BRR 偏小约 14%
     *    —— 结果当然还是乱码。**"总量÷已知个数"永远比"逐段平均"稳**。
     * ------------------------------------------------------------------ */
#define CAL_BYTES 64u /* PC 每次校准固定发这么多字节（必须与 PC 侧一致） */

    SysTick->LOAD = 0xFFFFFFu; /* 自由运行、不产生中断：只当 HCLK 周期计数器 */
    SysTick->VAL = 0;
    SysTick->CTRL = SysTick_CTRL_CLKSOURCE_Msk | SysTick_CTRL_ENABLE_Msk;
    USART1->CR1 |= USART_CR1_RE; /* 打开接收 */

    {
        uint32_t t_first = 0;
        uint32_t t_last = 0;
        uint32_t got = 0;
        uint32_t idle = 0;
        uint32_t wait = 0;

        /* ① 等第一个字节（开始计时） */
        while (wait < 300000000u) {
            wait++;
            if (USART1->SR & USART_SR_RXNE) {
                (void)USART1->DR;
                t_first = SysTick->VAL;
                t_last = t_first;
                got = 1;
                break;
            }
        }

        /* ② 继续收，直到出现一段足够长的静默（认为整束结束） */
        if (got > 0u) {
            for (;;) {
                if (USART1->SR & USART_SR_RXNE) {
                    (void)USART1->DR;
                    t_last = SysTick->VAL;
                    got++;
                    idle = 0;
                } else {
                    idle++;
                    if (idle > 300000u) { /* 约 0.1 秒静默 → 收完了 */
                        break;
                    }
                }
            }
        }

        char buf[80];
        char *q = buf;
        q = put_str(q, "CAL got=");
        q = put_u32(q, got);

        if (got > 0u) {
            /* SysTick 递减：t_first - t_last = 整束占用的 HCLK 周期数 */
            uint32_t span = (t_first - t_last) & 0xFFFFFFu;
            uint32_t brr = span / ((CAL_BYTES - 1u) * 11u); /* 用已知字节数当除数 */
            q = put_str(q, " span=");
            q = put_u32(q, span);
            q = put_str(q, " brr=");
            q = put_u32(q, brr);
            q = put_str(q, " hclk=");
            q = put_u32(q, brr * 115200u);
            q = put_str(q, "\r\n");
            *q = '\0';
            if (brr >= 1u && brr <= 0xFFFFu) {
                USART1->CR1 = 0;
                USART1->BRR = (uint16_t)brr; /* ← 波特率现在配对了 */
                USART1->CR1 = UART_CR1_8E1;
            }
        } else {
            q = put_str(q, " TIMEOUT（没收到字节）\r\n");
            *q = '\0';
        }
        board_early_puts(buf);
        board_early_puts("CAL done 0123456789ABCDEFGHIJKLMNOPQRSTUVWXYZ\r\n");
    }

    for (;;) { } /* 停在这里，等桥把结果读走 */
#else
    board_init();
    BOOT_MARKER = MARK_BOARD_INITED;

#if ALLOW_IRQ
    /* 诊断路标：这一行能出来 = 在**中断已开**的情况下活着走出了 board_init
     * （也就是 systick_init() 设了 TICKINT 之后没有立刻风暴）。
     * 它出不来 = 死在 board_init 内部，再往前一步就是 systick_init()/servo_init()。 */
    uart_puts("LOG diag alive-after-board_init irq=on\r\n");
#endif

    /* ---- 关键寄存器快照进 RAM ----------------------------------------
     * 外设寄存器（RCC/USART）不方便用 bootloader 直接读（实测有的地址会被 NACK），
     * 但 **RAM 一直可读**。所以把应用当时的真实配置抄一份到 RAM，
     * "复位回 bootloader → 读 0x20004810" 就能看到它到底把时钟和串口配成了什么。
     * 地址安排（不与 BOOT_MARKER @0x20004800 冲突）：
     *   +0x10 RCC_CFGR   +0x14 RCC_CR   +0x18 USART1->BRR   +0x1C USART1->CR1
     * ------------------------------------------------------------------ */
    {
        /* ⚠️ 2026-10-04：地址随 BOOT_MARKER 一起从 RCT6 的 0x2000B010 挪到 C8T6 合法的
         *    **0x20004810** —— 原来那个地址超出 20KB RAM ✗，一写就 HardFault ✓（见 boot_marker.h） */
        volatile uint32_t *dump = (volatile uint32_t *)0x20004810u;
        dump[0] = RCC->CFGR;
        dump[1] = RCC->CR;
        dump[2] = (uint32_t)USART1->BRR;
        dump[3] = (uint32_t)USART1->CR1;
    }

    s_state = ST_IDLE_UNHOMED; /* M1 没有上电自检，直接进"未回零空闲" */

    /* ---- 波特率自检（诊断代码，已结案，默认关闭）--------------------------
     * 同一句话用 9 个不同的 BRR 各发一遍。只有 BRR 恰好等于 f_cpu / 115200 的那一遍，
     * 在 PC 上才能读通 → **读到哪一行就知道 f_cpu = 115200 × 那个 BRR**。
     *
     * 🎯 2026-09-22 结案记录：打开后实测 **只有 `PROBE brr=69` 那一行是干净的**
     *    → f_cpu = 115200 × 69 = 7.95MHz，即 8MHz 主频没问题、BRR=69 也一直是对的。
     *    这条结论把"波特率/主频偏差"彻底排除，从而把注意力逼到**帧格式**上，
     *    最终查出真凶是 CR1.M 的字长语义（见 board.h 的 UART_CR1_8E1 注释）。
     *
     * ⚠️ 注意：这段代码会**用错误的 BRR 连续发 9 行**，所以打开时 boot 输出会
     *    有约 6 秒的乱码。正式固件保持关闭。 */
#define PROBE_BOOT 0
#if PROBE_BOOT
    {
        static const uint16_t probes[9] = {55, 60, 65, 69, 75, 80, 85, 89, 95};
        BOOT_MARKER = MARK_PROBE_ENTER;
        for (int i = 0; i < 9; i++) {
            char buf[64];
            char *q = buf;
            q = put_str(q, "PROBE brr=");
            BOOT_MARKER = MARK_PROBE_STR + (uint32_t)i;
            q = put_u32(q, probes[i]);
            BOOT_MARKER = MARK_PROBE_NUM + (uint32_t)i;
            q = put_str(q, " abcdefghijklmnopqrstuvwxyz 0123456789\r\n");
            *q = '\0';
            USART1->CR1 = 0;
            USART1->BRR = probes[i];
            USART1->CR1 = UART_CR1_8E1;
            uart_puts(buf);
            BOOT_MARKER = MARK_PROBE_SENT + (uint32_t)i;
            for (volatile uint32_t d = 0; d < 400000u; d++) { } /* 拉开间隔便于分辨 */
        }
        BOOT_MARKER = MARK_PROBE_DONE;
        /* 恢复成"按 8MHz 算"的正常配置 */
        USART1->CR1 = 0;
        USART1->BRR = (8000000u + 115200u / 2u) / 115200u;
        USART1->CR1 = UART_CR1_8E1_RX;
    }
#endif /* PROBE_BOOT */

    /* 上电横幅：这是"固件真的跑起来了"的第一手证据（桥的 serial_read 能看到），
     * 不依赖我们主动发命令。 */
    reply("LOG boot fw=" FW_VERSION " proto=" PROTO_VERSION);
    BOOT_MARKER = MARK_BANNER_DONE;

#if HEARTBEAT
    /* ------------------------------------------------------------------
     * 心跳诊断：持续重复输出一行**已知内容**，每 1 秒一行。
     *
     * 为什么需要它：排查"串口乱码"最痛的一点是**固件只在启动瞬间说话**，
     * 想抓那几十个字节就得先复位一次，而这块板子的复位通路（CH340 自动 ISP
     * 电路 → NRST）到底靠 DTR 还是 RTS、是电平还是边沿，一直没搞清楚 ——
     * 于是每一轮排查都在"复位没成功 / 抓到 0 字节"上反复浪费。
     * 改成持续输出后，**任何时候打开串口都能立刻看到结果**，不需要复位。
     *
     * 内容里同时放数字和大小写字母：数字能看出"高位有没有被多置 1"
     * （波特率偏差的典型指纹），字母能看出整体可读性。
     * 排查结束后把 HEARTBEAT 改回 0 即可。
     * ------------------------------------------------------------------ */
    for (;;) {
        uart_puts("HB 0123456789 abcdefghijklmnopqrstuvwxyz ABCDEFGHIJKLMNOPQRSTUVWXYZ\r\n");
        for (volatile uint32_t d = 0; d < 900000u; d++) { }
    }
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

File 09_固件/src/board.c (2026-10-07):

/* M1 固件 —— 板级支持（时钟 / 滴答 / GPIO / USART1）
 *
 * 全部用 CMSIS 的寄存器定义直接编程，不依赖标准外设库（SPL）：
 * M1 只需要 4 个外设（RCC/GPIO/USART/SysTick），引 SPL 反而增加构建面。
 *
 * 引脚（与《固件设计-协议与引脚》§8 一致）：
 *   PA9  USART1_TX  → 板载 CH340K → PC 的 COM 口
 *   PA10 USART1_RX
 * 串口参数 **115200 8E1**（偶校验，与出厂 bootloader 一致，见 usart_baud 注释）。
 *
 * ⚠️ 本文件最重要的设计原则：**永远不要"悄悄地卡住"**。
 *    HSE 晶振不起振、PLL 不锁定这类故障，如果只写死等循环，表现就是"板子毫无反应"，
 *    排查代价极高。所以这里每一步都带超时，并且**先把串口跑起来再切主频**，
 *    保证任何阶段出问题都能吐出一行可读的诊断。
 */

#include "board.h"

#include "boot_marker.h"
#include "stm32f10x.h"

/* 目标主频。不复用 DFP 的 SystemCoreClock —— 那个符号来自 system_stm32f10x.c，
 * 而本工程刻意不编译它。改 PLL 倍频就必须同时改这里，否则 SysTick 和波特率会一起错。 */
#define CPU_HZ_HSI 8000000u
#define CPU_HZ_PLL 72000000u

/* M1 先**不用 PLL**，就跑在 HSI 8MHz 上。
 *
 * 原因：2026-09-21 实测发现——用 PLL 时 PC 收到的全是乱码，且乱码呈"前 7 位正确、
 * 第 8 位起漂移"的形态，这是波特率偏差约 8% 的典型特征。而"晶振到底是不是 8MHz"
 * 既没有丝印可读、也没有示波器可量。所以 M1 阶段先把时钟源固定成 HSI 这一个，
 * 用 main() 里的"波特率自检"把它测准，再决定 PLL 怎么配。
 *
 * 为什么可以先不追时钟精度：M1 只做串口协议与状态机，8MHz 完全够。
 * 步进脉冲引擎（M3）才真正需要高主频 —— 那时这个数已经测准了。
 */
#define USE_PLL 0

/* M1 阶段：SYSCLK 用**板上晶振（HSE 8MHz）**而不是 HSI。
 *
 * 2026-09-22 实测定位：HSI 这块片子偏了约 5%（PROBE 自检里 BRR=69 与 75 两档都只是
 * "勉强能读"，对应 f_cpu ≈ 115200×73 ≈ 8.4MHz）。而 8E1 只有 1 位停止位，波特率
 * 容差本来就只有 ±2% 左右。5% 偏差的症状极有迷惑性：**帧结构完全正确**（\r\n 原样、
 * 字符位置一一对应、低半字节基本都对），只有每个字节靠后的几位采错 ——
 * 看起来就是"字符大体认识、高位时不时多一个 1"，非常容易被误判成"干扰"或"帧格式错"。
 * 换晶振（±30ppm）后 BRR=69 的误差只有 0.6%，问题从根上消失。
 * 注意 HSE 与 HSI 同为 8MHz，所以切换前后 BRR 不用改。 */
#define USE_HSE 1

#define UART_BAUD 115200u

/* 临时实验开关：强制 BRR 为固定值（0 = 不用，走自校准）。
 * 2026-09-22 实测：**69 和 70 都试过，输出都是乱码** → 排除"单纯波特率偏一个数"的可能，
 * 说明还有别的因素（详见 Claude接续日志.md 的排查记录）。已还原为 0。 */
#define BRR_FORCE 0u

/* 波特率自校准开关：0 = 关（M1 阶段已改用晶振 HSE，不需要再校准）。
 *
 * 为什么要关：这个函数是为了对付"HSI 偏差导致 BRR 处于容差边缘"而写的，
 * 但它一直没真正生效（实测 BRR 仍是 69），而且**每次启动都要死等 ~10 秒**
 * （等主机发 64 个字节来测时长）—— 排查时这 10 秒会严重拖慢每一轮
 * "编译→烧录→抓包"的迭代。改用晶振后它的前提也不成立了。
 * 保留代码与开关，将来若真要支持"无晶振板"再启用。 */
#define AUTOCAL 0

/* M1 用**轮询**收字节，不开接收中断。
 *
 * 为什么：2026-09-21 实测发现——一旦在 board_init 末尾 `__enable_irq()`，
 * main 里第一次 uart_puts 就卡死在 TXE 轮询上（而中断关闭时同一函数完全正常）。
 * M1 的主循环本来就无事可做，轮询在 115200 下不会丢字节（一字节 87µs，
 * 主循环一圈只有几条指令），所以先用轮询把通信与协议跑通。
 *
 * 中断收字节的能力**保留在代码里**（`UART_RX_IRQ 1` 即可切回），
 * 留到 M3 —— 那时步进引擎必须用定时器中断，有明确的时序需求，
 * 才好一并判断优先级、临界区与中断嵌套。先解决"能动"，再解决"快"。 */
/* M1 曾用**轮询**收字节，不开接收中断。2026-09-22 起**默认开接收中断**。
 *
 * 历史：2026-09-21 记录"一旦在 board_init 末尾 `__enable_irq()`，main 里第一次
 * uart_puts 就卡死在 TXE 轮询上"，于是关掉中断绕过去。
 * **2026-09-22 实测订正（线路 A）**：那是**误判** —— 真凶是**向量表下标错位**
 * （USART1 的向量被放在 IRQn 21、真正的 IRQn 37 是 0，见 startup.c 第 89-93 行）：
 * 一开中断 + RX 线上一个噪声起始位 → 跳到地址 0 跑飞，卡死正好落在随后的
 * 第一次 uart_puts 上。该错误已修，实验 1（只剩 SysTick）与实验 2（SysTick +
 * USART1 RX 都开）**双双通过**：banner 完整、`PING → OK pong`。
 * → 现在**开中断**：M3 的步进引擎必须用定时器中断，中断路径必须常态可用；
 *   而且中断收字节比轮询更抗主循环变慢（M3 主循环会忙起来）。
 *   置 0 仍可用于"怀疑中断时快速排除"。 */
#define UART_RX_IRQ 1

/* 死等循环的兜底次数：约几十毫秒量级。宁可报错降频，也不要无声卡死。 */
#define WAIT_GUARD 2000000u

/* --------------------------------------------------------------------------
 * 接收环形缓冲区
 * 中断里只做"塞进缓冲区"这一件事（够快、不丢字节），解析放到主循环。
 * 单生产者（中断）单消费者（主循环）、容量是 2 的幂、无符号回绕比较，
 * 因此 head/tail 各写各的，不需要临界区。
 * ------------------------------------------------------------------------ */
#define RXBUF_SIZE 256u /* 必须是 2 的幂 */
static volatile uint8_t s_rx[RXBUF_SIZE];
static volatile uint32_t s_rx_head;
static volatile uint32_t s_rx_tail;

static volatile uint32_t s_millis;
static uint32_t s_cpu_hz = CPU_HZ_HSI; /* 实际主频；波特率换算依赖它 */

/* --------------------------------------------------------------------------
 * 串口底层
 * ------------------------------------------------------------------------ */
static void uart_apply_baud(uint32_t cpu_hz)
{
    /* STM32 的 BRR 是定点数：BRR = f_cpu / 波特率（四舍五入），
     * 等价于 USARTDIV = f/(16*baud) 后再 <<4。
     * 例：72e6/115200 = 625 整；8e6/115200 = 69.44 → 69（误差 0.6%，可接受）。 */
    uint32_t brr = (cpu_hz + UART_BAUD / 2u) / UART_BAUD;

#if BRR_FORCE
    brr = BRR_FORCE; /* 临时实验：见 BRR_FORCE 定义处的说明 */
#endif

    USART1->CR1 = 0; /* 改配置前先关 UE，避免半个字节的毛刺 */
    USART1->BRR = brr;
    /* 115200 **8E1（偶校验）**：与出厂 ROM bootloader 保持一致 ——
     *   ① 烧录与应用通信只用一种参数，不必切换（切换要重开端口，而重开会经自动
     *      ISP 电路复位板子，极易自乱阵脚）；
     *   ② 偶校验给"电机干扰导致字节翻位"提供一道几乎免费的检测。
     * 注意 F1 的极性：CR1.PS = 0 才是**偶**校验（PS=1 是奇校验），这里不置 PS。 */
    USART1->CR1 = UART_CR1_8E1_RX;
}

static void uart_gpio_init(void)
{
    RCC->APB2ENR |= RCC_APB2ENR_IOPAEN | RCC_APB2ENR_USART1EN;
    /* CRH 每 4 位管一个引脚，引脚 n（8~15）占 bit[4*(n-8) .. 4*(n-8)+3]：
     *     PA9  → bit[7:4]  = 0xB → 复用推挽输出、50MHz   （USART1_TX）
     *     PA10 → bit[11:8] = 0x4 → 浮空输入              （USART1_RX）
     *   合起来 = (0xB << 4) | (0x4 << 8) = 0x4B0
     *
     * ⚠️ 血泪教训：这里最初误写成 0xB40，**把 TX 和 RX 的高低位搞反了** ——
     *    PA9 变成浮空输入、PA10 变成推挽输出。症状极具迷惑性：USART 内部照常
     *    移位（TXE/TC 正常置位、发送函数正常返回），但**信号根本没到引脚**，
     *    表现就是"固件明明在跑、却收不到任何字节"。查了很久才想起来手算这个半字。
     */
    GPIOA->CRH = (GPIOA->CRH & ~0x00000FF0u) | 0x000004B0u;
}
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

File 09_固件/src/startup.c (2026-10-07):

/* M1 固件 —— 启动与中断向量表
 *
 * 设计取舍：**不使用 DFP 自带的 armasm 启动文件**，全部用 C 写。
 * 这样工具链只需要 armclang 一个编译器，不必处理 armasm 的条件汇编语法差异，
 * 而且每一行都能被 C 编译器检查。
 *
 * 启动流程：硬件从向量表取 SP 和 Reset_Handler → 本文件的 Reset_Handler → 调 __main
 *          → 由 armlink 的 C 库完成 scatter 加载（把 RW 从 flash 拷到 RAM、把 ZI 清零）
 *          → 进入 main()。
 *
 * ⚠️ 时钟切换（HSI 8MHz → HSE+PLL 72MHz）**不在**这里做，而在 main() 里：
 *    scatter 加载很快、不依赖主频，先让 C 运行时把环境准备好更稳。
 */

#include "boot_marker.h"
#include "stm32f10x.h"

/* ⚠️ 2026-10-04：板子从 **RCT6（48KB SRAM）换成 C8T6（20KB SRAM）**
 *    → 栈顶从 0x2000C000 改成 **0x20005000**（0x20000000 + 20KB）。
 *    必须和 m1.scf 里的 RW_IRAM1 配套：RW/ZI 14KB（到 0x20003800）+ 栈 6KB。 */
#define STACK_TOP 0x20005000u /* C8T6：RAM 顶端 = 0x20000000 + 20KB */

extern int main(void);

/* armlink 按 m1.scf 里的区域名自动生成的符号（`$` 是 ARM 工具链的合法标识符扩展，
 * armclang 实测可编译）。用它们自己完成 RW 拷贝 / ZI 清零，替代 __main 的 scatter 加载。 */
extern uint32_t Load$$RW_IRAM1$$Base[];
extern uint32_t Image$$RW_IRAM1$$Base[];
extern uint32_t Image$$RW_IRAM1$$ZI$$Base[];
extern uint32_t Image$$RW_IRAM1$$ZI$$Limit[];

/* --------------------------------------------------------------------------
 * 中断处理函数：这里只给**弱定义**（死循环/空），需要真正实现的中断
 * （USART1、SysTick）在 board.c 里强定义覆盖。
 * 注意：中断名必须与向量表里的名字一致，链接器才会用强定义替换弱定义。
 * ------------------------------------------------------------------------ */
extern void board_early_uart(void);
extern void board_early_puts(const char *text);

/* 启动脚印（BOOT_MARKER / MARK_*）的说明见 boot_marker.h —— 它是排查
 * "板子毫无反应"这类问题的主力手段。 */

/* 故障也让它开口 —— 一个"死得悄无声息"的单片机是最难查的。
 * 这几句只依赖已经配好的 USART 寄存器，不依赖任何全局变量，因此在早期也安全。
 *
 * 2026-10-03 升级：光印一行 "HARDFAULT" 定位不了任何问题（K210 一收数据就跑飞，
 * 却不知道跑飞到哪）。现在把 **CFSR/HFSR/BFAR/MMFAR + 出错时的 PC/LR** 一起印出来：
 *   · CFSR 的哪一位 = 什么错（IBUSERR/PRECISERR/IMPRECISERR/UNDEFINSTR/UNALIGNED…）
 *   · BFAR/MMFAR 有效时 = 访问的坏地址
 *   · PC = 出错那条指令的地址（拿它去 build\m1.axf 用 fromelf -c 反汇编就能对到函数）
 * 寄存器用**绝对地址**访问，不依赖 CMSIS 头，免得在故障路径里再引入依赖。 */
static void fault_hex(const char *tag, uint32_t v)
{
    static const char hexd[] = "0123456789abcdef";
    char buf[11];
    int i;

    for (i = 0; i < 8; i++) {
        buf[7 - i] = hexd[(v >> (i * 4)) & 0xFu];
    }
    buf[8] = '\0';
    board_early_puts(tag);
    board_early_puts(buf);
}

__attribute__((weak)) void HardFault_Handler(void)
{
    volatile uint32_t *cfsr  = (volatile uint32_t *)0xE000ED28u; /* CFSR  */
    volatile uint32_t *hfsr  = (volatile uint32_t *)0xE000ED2Cu; /* HFSR  */
    volatile uint32_t *mmfar = (volatile uint32_t *)0xE000ED34u; /* MMFAR */
    volatile uint32_t *bfar  = (volatile uint32_t *)0xE000ED38u; /* BFAR  */
    uint32_t exc_return;
    uint32_t *frame;
    uint32_t msp;

    BOOT_MARKER = MARK_FAULT_HARD;
    board_early_puts("LOG fault=HARDFAULT\r\n");

    fault_hex("LOG fault cfsr=0x", *cfsr);
    fault_hex(" hfsr=0x", *hfsr);
    board_early_puts("\r\n");
    fault_hex("LOG fault mmfar=0x", *mmfar);
    fault_hex(" bfar=0x", *bfar);
    board_early_puts("\r\n");

    /* 异常返回码的 bit2：0 = 用的是 MSP，1 = PSP。本项目没有 RTOS，正常都是 MSP。
     * 栈帧里 [6] = PC（出错指令）、[5] = LR、[7] = xPSR。 */
    __asm volatile ("mov %0, lr" : "=r" (exc_return));
    __asm volatile ("mrs %0, msp" : "=r" (msp));
    if ((exc_return & 0x4u) == 0u) {
        frame = (uint32_t *)msp;
        fault_hex("LOG fault pc=0x", frame[6]);
        fault_hex(" lr=0x", frame[5]);
        fault_hex(" psr=0x", frame[7]);
        board_early_puts("\r\n");
    }

    for (;;) { } /* 停在这里，方便接调试器看现场 */
}
__attribute__((weak)) void NMI_Handler(void)
{
    BOOT_MARKER = MARK_FAULT_NMI;
    board_early_puts("LOG fault=NMI\r\n");
    for (;;) { }
}
__attribute__((weak)) void MemManage_Handler(void) { BOOT_MARKER = MARK_FAULT_MEM; board_early_puts("LOG fault=MEM\r\n"); for (;;) { } }
__attribute__((weak)) void BusFault_Handler(void) { BOOT_MARKER = MARK_FAULT_BUS; board_early_puts("LOG fault=BUS\r\n"); for (;;) { } }
__attribute__((weak)) void UsageFault_Handler(void) { BOOT_MARKER = MARK_FAULT_USAGE; board_early_puts("LOG fault=USAGE\r\n"); for (;;) { } }
__attribute__((weak)) void SVC_Handler(void) { for (;;) { } }
__attribute__((weak)) void DebugMon_Handler(void) { for (;;) { } }
__attribute__((weak)) void PendSV_Handler(void) { for (;;) { } }
__attribute__((weak)) void SysTick_Handler(void) { }
__attribute__((weak)) void USART1_IRQHandler(void) { }
__attribute__((weak)) void USART2_IRQHandler(void) { }
__attribute__((weak)) void TIM4_IRQHandler(void) { }   /* M3 步进脉冲发生器（IRQn 30） */
__attribute__((weak)) void USART3_IRQHandler(void) { } /* 视觉板 K210（IRQn 39，C8T6 上就是它） */

void Reset_Handler(void);

/* --------------------------------------------------------------------------
 * 向量表。放进名为 "RESET" 的段，由 m1.scf 的 `*(RESET, +First)` 钉在
 * flash 最开头 0x08000000 —— 这是硬件规定的位置，摆错就永远起不来。
 *
 * 偏移 0x00 是**初始 SP 的值**（不是函数指针），从 0x04 起才是函数指针。
 * ------------------------------------------------------------------------ */
__attribute__((section("RESET"), used))
const uint32_t g_vectors[] = {
    STACK_TOP,                          /* 0x00 初始栈顶 */
    (uint32_t)Reset_Handler,            /* 0x04 复位 */
    (uint32_t)NMI_Handler,              /* 0x08 */
    (uint32_t)HardFault_Handler,        /* 0x0C */
    (uint32_t)MemManage_Handler,        /* 0x10 */
    (uint32_t)BusFault_Handler,         /* 0x14 */
    (uint32_t)UsageFault_Handler,       /* 0x18 */
    0, 0, 0, 0,                         /* 0x1C~0x28 保留 */
    (uint32_t)SVC_Handler,              /* 0x2C */
    (uint32_t)DebugMon_Handler,         /* 0x30 */
    0,                                  /* 0x34 保留 */
    (uint32_t)PendSV_Handler,           /* 0x38 */
    (uint32_t)SysTick_Handler,          /* 0x3C */
    /* 外部中断：**数组下标 = 16 + IRQn**（前 16 项是内核异常）。
     * 本项目 M1 只用到 IRQn 37 = USART1。
     *
     * ⚠️ 血泪教训：这里最初写成 `[37] = USART1_IRQHandler`，等于把 USART1 的向量
     *    放到了 IRQn 21（CAN_RX1）的位置，而**真正的 IRQn 37 位置仍然是 0**。
     *    后果：NVIC_EnableIRQ(USART1_IRQn) 一开中断，一旦有事件就跳到地址 0 跑飞，
     *    现象是"程序莫名卡死"，而不会报任何错 —— 因为这个 16 的偏移完全合法，
     *    编译器也不会警告。将来加 TIM4(30)、EXTI(23) 时同样要 +16。 */
    [16 ... 52] = 0,                            /* IRQn 0 ~ 36 */
    [16 + 30] = (uint32_t)TIM4_IRQHandler,      /* IRQn 30 = TIM4（M3 步进脉冲发生器） */
    [16 + 37] = (uint32_t)USART1_IRQHandler,    /* IRQn 37 = USART1（板载 CH340K 调试口） */
    [16 + 38] = (uint32_t)USART2_IRQHandler,    /* IRQn 38 = USART2（无线桥 C6） */
    [16 + 39 ... 16 + 59] = 0,                  /* IRQn 39 ~ 59 */
    /* ⚠️⚠️ 2026-10-03 血的教训（**指定初始化器是"后面覆盖前面"的**）：
     *    最初把 `[16 + 52] = UART4_IRQHandler` 写在上面那行 `[16 + 39 ... 16 + 59] = 0` **之前**，
     *    结果被后面这行**又清成了 0** ⇒ **UART4 的向量 = 0**。
     *    症状：一收到 K210 的数据就 **HardFault**，`CFSR` 的 bit17 = **INVSTATE**
     *    （跳到地址 0 = 一个非 Thumb 地址）。
     *    ⇒ **凡是"区间清零"必须放在所有具体条目之前**；具体条目一律放最后。
     *    （USART1/2 的 37/38 和 TIM4 的 30 都不在那个区间内，所以一直没暴露。） */
    [16 + 39] = (uint32_t)USART3_IRQHandler,    /* IRQn 39 = USART3（视觉板 K210） */
};
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

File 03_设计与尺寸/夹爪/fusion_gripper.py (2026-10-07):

# -*- coding: utf-8 -*-
"""
工创赛 II-2 智能分拣 —— 龙门 XYZ 末端「平行两指夹爪」参数化建模脚本
================================================================================
在 Autodesk Fusion 360 里一键生成夹爪实体模型（每个零件一个独立元件，方便单独
查看 / 出说明书插图 / 导出 STEP / STL 去 3D 打印）。

用法：
    Fusion 360 → 实用程序(Utilities) → 附加模块(Add-Ins) → 脚本和附加模块
    → 「脚本」标签 → 绿色「+」→ 选中本文件 → 运行(Run)

坐标系（全部毫米）：
    X = 两爪开合方向    Y = 夹爪深度方向    Z = 竖直向上（Z=0 为爪尖底面）
    原点 = 两爪夹持中心 × 爪板深度中心 × 爪尖底面高度
    建模姿态 = 最大开口 64mm

【建模手法（全脚本统一，不出现任何复杂坐标换算）】
  · 每个零件在自己元件的「局部坐标系」里以原点为基准、用最笨的正交草图建模，
    需要偏移时再用 occurrences 的 Matrix3D 平移到位。
  · 只用 3 个基准构造平面：
        XY（法向 +Z）：用于竖向尺寸（沿 Z 拉伸）与所有立体/槽口
        XZ（法向 -Y）：用于 (X, Z) 平面轮廓（沿 Y 拉伸），齿轮/齿条/爪板全走这条
        YZ（法向 +X）：用于画圆做沿 X 的孔/杆
  · 截面轮廓 = sketchLines.addByTwoPoints 连成闭合 4/多段线 → extrudeFeatures
  · 齿廓 = 20° 压力角梯形直线近似，齿顶宽 = 0.5×模数
  · 每个零件独立 try/except：单个零件失败只记录，不会让整个脚本崩掉
"""

import math

import adsk.core
import adsk.fusion
import traceback

# =============================================================================
# ============================ 一、参数区（改这里）============================
# =============================================================================

# ------------------------------------------------------------------ 1. 总体
OPEN_MAX = 64.0        # 最大开口：两爪内侧面间距（建模姿态）
CLOSE_MIN = 8.0        # 最小开口
STROKE_TOTAL = 56.0    # 全行程 = 64 - 8
STROKE_ONE = 28.0      # 单爪行程 = 全行程 / 2（对置齿条自定心）

# ------------------------------------------------------------ 2. 爪板（2只）
JAW_THICK = 3.5        # 爪板厚
JAW_DEPTH = 30.0       # 爪板深（Y）
JAW_HEIGHT = 48.0      # 爪板高：夹持面 Z 0~48
JAW_WEDGE_H = 12.0     # 爪尖楔形高度（Z 0~12 内收）
JAW_TIP_THICK = 1.5    # 爪尖最下端厚度（Z=0 处）
JAW_PLATE_DX = 32.0    # 爪板内侧面（夹持面）位置：X = ±32
ROD_HOLE_Z = 12.0      # 导杆中心高度（Z）：也是爪板连接耳上 Ø6 孔的中心高
ROD_HOLE_D = 6.0       # 爪板上导杆通孔直径（打印后会缩孔，见文末备注 5）
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

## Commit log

2026-10-07 Initial backup: full project (firmware, hw_bridge, vision, screen, docs)
    [Follower gripper (165x165 bed size).STL, Follower gripper (165x16_01_128x60x24.stl, Follower gripper (165x16_02_101x34x52.stl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]
2026-10-07 删除文件 Claude接续日志.md
2026-10-07 Untrack Claude接续日志.md (keep local only, add to .gitignore)
2026-10-07 删除文件 00_待办与拍板
2026-10-07 删除文件 08_发给队友
2026-10-07 重命名 12_视觉 为 8_视觉
2026-10-07 重命名 8_视觉 为 08_视觉
2026-10-07 重命名 11_ESP无线 为 11_ESP无线调试
2026-10-07 Untrack internal dirs 00_待办与拍板, 08_发给队友 (keep local only)
2026-10-07 Update README paths after web-ui reorganization (08_视觉, 11_ESP无线调试)
2026-10-08 添加models
2026-10-08 添加models文件夹
    [-龙门架钢轨固定-实体一已镜像.SLDPRT, -龙门架钢轨固定-实体二已镜像.SLDPRT, 00_ARM-L_7.stl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]
2026-10-08 fw 0.8.2: move Y step PUL from PA5 to PA12 (PA5 pin damaged); real X42 header naming (Stp/Dir/En/Com); M3? adds acrh; manual console M/T diagnostics
2026-10-19 fix: remap Y-axis pulse pin to PA12; rewrite shape classifier; harden port/camera autodetect
    Y-axis PUL moved PA5 -> PA12 (PA5 pin found dead: correct CRL config and step counting, but no pulses on the pin). M3? now also reports acrh so the new pin's config is verifiable.
    pc_detect.shape_of rewritten: the old approxPolyDp vertex-count rule flipped between hexagon/poly7x/circle/square-ish on consecutive photos of the same item. New rule = angular symmetry order (FFT of the ray-edge radial profile on the convex hull) plus an ellipse-residual test, so a top-view regular polygon and a tilted-view cylinder are separated by structure, not by vertex noise. Adds shape_probe.py to print hull/harmoni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
2026-10-19 chore: untrack vendored libraries, firmware build output and internal scratch dirs
    - hw_bridge/vendor* (pyserial, esptool, mpremote ...): ~1260 third-party files were copied into the repo. They are now installed via hw_bridge/requirements.txt instead, so the repository stays readab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
    - 09_固件/build/: compiler objects, .axf/.bin and flash log are build output, not source. Rebuild with 09_固件/build.py.
    - _work/ and _download/: local scratch and a duplicated third-party copy (SSG48); the curated copy stays in 06_参考与开源/.
    - _vp.jpg: camera capture used for calibration, not a docu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
2026-10-19 fix: repair stale vision paths and hardcoded camera port
    After the 12_视觉 -> 08_视觉 rename and the USB port reshuffle, several tools still pointed at the old location or defaulted to COM5. calibrate_2point.py could not run at all (shot.py path missing). All tracked text files under 08_视觉/ and hw_bridge/tools/ now use 08_视觉; calibrate_2point.py gets --k210 auto (shared find_k210 from vision_pick) and the same patient two-round port probe used by pick_place/go_safe.
2026-10-19 chore: untrack leftover development logs
    08_视觉/shots/*.log are serial/camera debug dumps, not project data.
2026-10-19 docs: add open-source landing page, reader guides, license and third-party notices
    README rewritten as a landing page: what the machine does, system architecture, hardware table, directory map, five-minute quick start, engineering notes worth borrowing, honest status/known issues, safety rules.
    New docs/: 00 reading paths and directory map, 01 step-by-step quick start (deps, firmware build/flash, manual console, calibration, picking), 02 FAQ built from the traps actually hit during the project (port renumbering, serial reset, open-loop false success, shape classifier instability, ExecutionPolicy, ...).
    LICENSE: MIT for our own work. THIRD_PARTY_NOTICES.md: SO-ARM gripper (CERN-OHL-P-2.0 ha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
